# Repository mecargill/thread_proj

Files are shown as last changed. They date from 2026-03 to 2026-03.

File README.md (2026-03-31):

# Thread Project
## Overview
This project is a wearable free fall detection system implemented on an ESP32. It uses ESP_IDF. 
## Repo Structure
The documentation folder contains a user guide, diagrams, and pictures. 
The enclosure folder contains .stl files for 3D printing the enclosure. 
The code folder contains 2 subfolders. The final firmware is in the node_final folder.
The final ui, as well as some helper Python programs, are in the data_proc folder. See code/data_proc/requirements.txt for the requirements for setting up the venv.

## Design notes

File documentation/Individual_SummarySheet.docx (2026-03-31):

Name: | Matthew Cargill
Thread: | Sensing and Exploration
Brief Project Description (2-3 sentences): | This project is a wearable-free, privacy-preserving fall detection system designed for elderly individuals. It uses a combination of vibration sensing, acoustic sensing, and Wi-Fi CSI to detect motion, sound, and floor vibrations associated with a fall. By integrating multiple sensing modalities, the system improves reliability compared to single-sensor approaches.
On-campus Resources used (Makerspaces, Instructional Labs) | The Hive Makerspace
Relation to thread (1-2 sentences): | This project directly aligns with the Sensing and Exploration thread by incorporating multiple sensing modalities, including Wi-Fi, vibration, and acoustic signals. It also applies sensor fusion techniques to interpret noisy data and improve fall detection accuracy.
Why did you choose this project? | I have known several relatives/friends who were seriously injured/died because of falls – it is important for them to get help as fast as possible. Additionally, my grandmother often refused to wear her Life Alert device, so I saw firsthand the difficulties of wearable solutions. I was also interested in exploring Wi-Fi sensing, which was a new and intriguing area to me.
Final Outcome (Was the project completed): | The project was completed successfully. The final system includes a soldered protoboard implementation housed in a 3D-printed enclosure. I also developed software to interface with the device and display a graphical dashboard showing presence detection, fall detection results, and event logs. Testing demonstrated that the system can detect both falls and presence with reasonable accuracy. However, this remains a prototype, and performance could be further improved with more advanced signal processing and modeling techniques.

Innovate ECE: The Ultimate Thread Competition Summary Sheet – Individual Submission Spring 2026

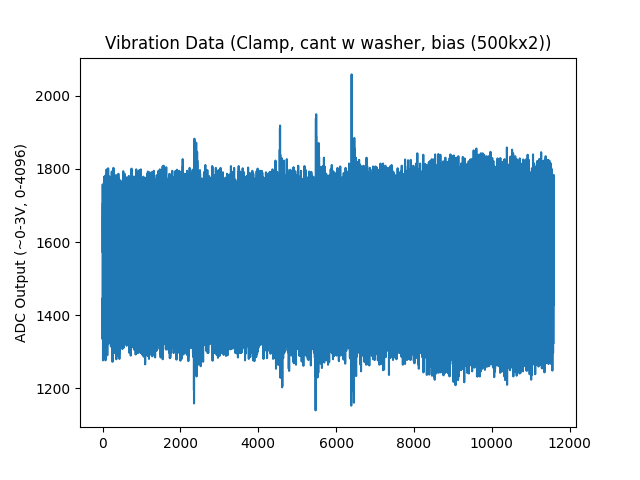
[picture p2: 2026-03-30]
documentation/pics/vib/Figure_2.png

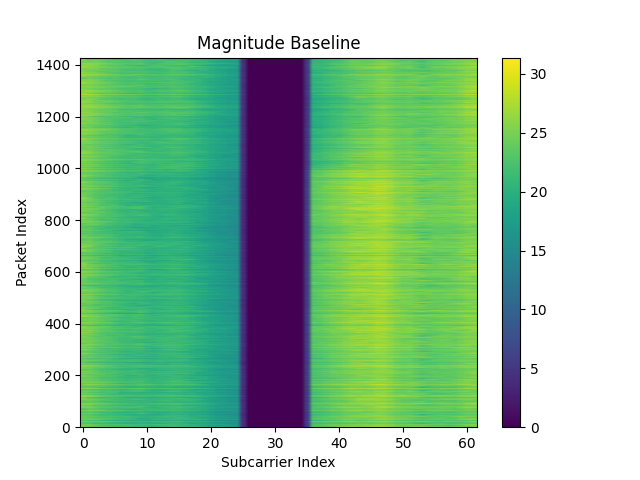
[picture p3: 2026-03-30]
documentation/pics/csi/baseline_w_dc.png

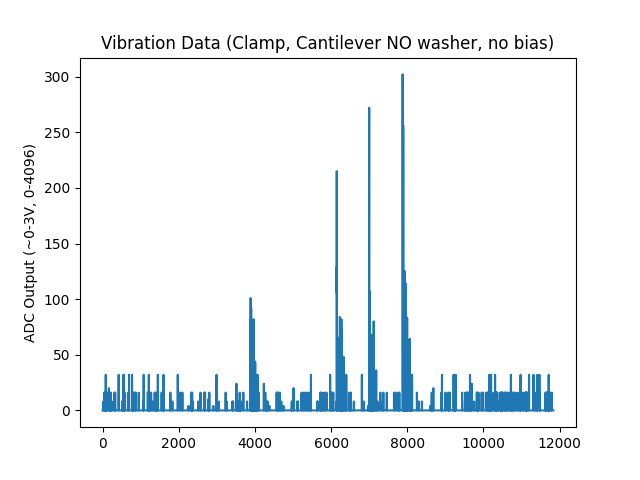
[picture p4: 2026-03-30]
documentation/pics/vib/Figure_6.png

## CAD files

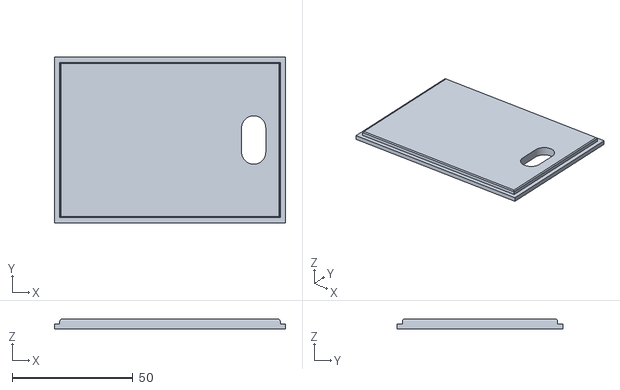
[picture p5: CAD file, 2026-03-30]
enclosure/enclosure_cap.stl
95.5 x 68.5 x 4.00

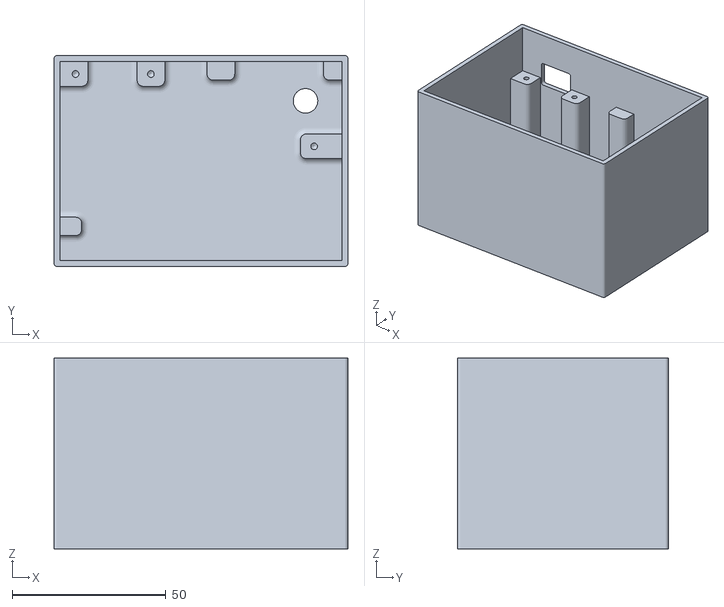
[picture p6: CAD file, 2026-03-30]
enclosure/enclosure_body.stl
95.5 x 68.5 x 62.0

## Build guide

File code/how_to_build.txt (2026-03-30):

open powershell
To build and run:
	export.ps1
	idf.py set-target esp32   (only once per project)
	idf.py menuconfig (TO ENABLE CSI IN component config->wifisettings, SET RTOS TICK to 500Hz not 100)
	idf.py build
	idf.py flash [-p COM5 (or similar)]
	idf.py monitor - to see program output
		ctrl+] to exit monitor mode

Miscellaneous
	idf.py fullclean - to clean build
	idf.py menuconfig
	idf.py create-project <project name>

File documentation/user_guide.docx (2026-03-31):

# Wearable-Free Fall Detection User Guide

# 1. Goals

The goal of this project is to use sensors to create an inexpensive fall detection system without wearables. The elderly often forget or choose not to put on health wearables, so a fall detection system that could be installed in a home or assisted living facility rather than worn could be more reliable. To preserve privacy, this project aims to avoid using cameras.

# 2. Overview of Design

### Hardware Overview

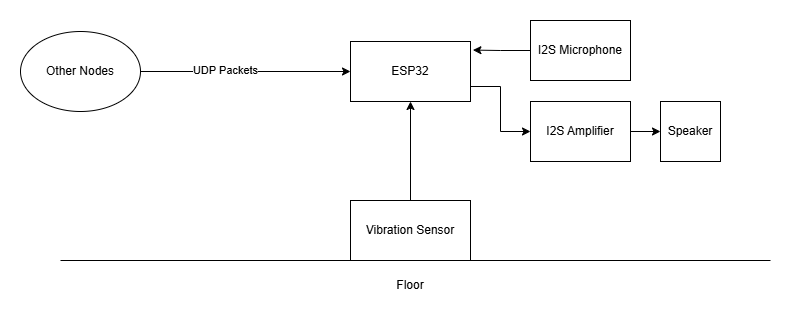
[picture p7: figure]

This system uses 3 types of sensing to detect a fall: a piezoelectric vibration sensor, a microphone, and Wi-Fi Channel State Information (CSI) sensing. The vibration sensor detects someone hitting the floor. The microphone detects the thump of a fall or presence in the room. The CSI data is used to detect changes in Wi-Fi signal propagation at different frequencies caused by motion (more information is in the resources section or here (https://www.digitalintelligence.at/wifi-signals-can-see-you-how-csi-sensing-works/)). An ESP32 will serve as the central hub where most of the processing will happen. Additionally, the speaker is used to play an alert when a fall is detected.

### Software Overview

There are 2 main sets of software in this project (repositories in resources section). The first is the C program (in repo node_final) running on the ESP32 which handles the following:

- Interfacing with microphone and speaker
- Reading and processing vibration data
- Sending and/or receiving packets
- Processing CSI data
- Depending on the mode, either streaming data for development/tuning purposes (development modes) or communicating only the results of processing to preserve privacy (normal operation mode)

The second set of software is written in Python and is run on a computer connected to the ESP32 development board’s UART to USB chip (in repo data_proc). There are multiple programs, which have the following functions:

- With ESP32 software in normal operation mode, act as a dashboard showing sensor activity and detection status
- Read/visualize streamed CSI data for development purposes
- Read/visualize streamed microphone data for development purposes
- Read/visualize streamed vibration data for development purposes

# 3. Components Required

The following components were used in this project:

- 2 ESP32 DEVKIT V1 boards
- INMP 441 Board (microphone)
- Piezoelectric Ceramic Disc
- MAX 98357 Amplifier Board
- 1 W, 8 Ohm speaker

The exact purchases are in the resources section.

# 4. Hardware Setup

Once the hardware is obtained, the connections shown below should be implemented. It is best to use a breadboard first for testing, then potentially create a more permanent implementation if desired. The provided CAD files can be used to 3D print an enclosure as well.

This setup only needs to be done on one of the ESP32s – the one which will be receiving the UDP packets and calculating the CSI.

### Connection Diagram

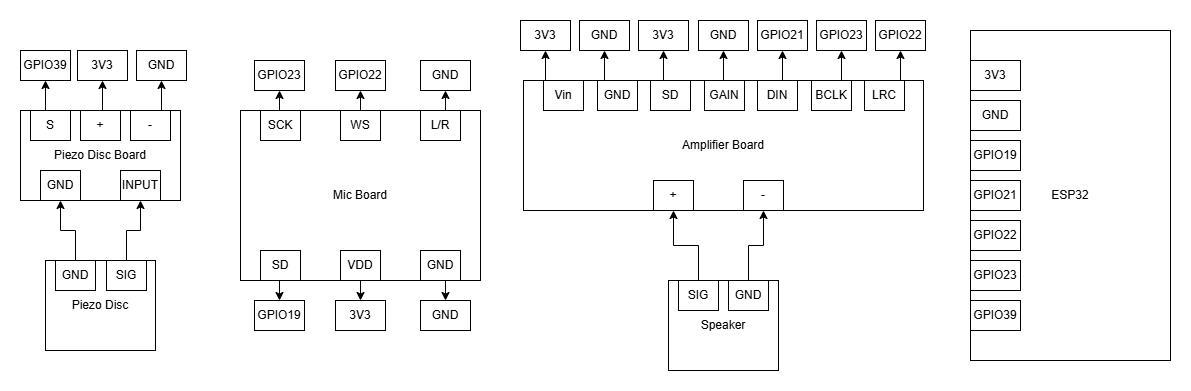
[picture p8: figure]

### DEVKIT V1 Pinout


### Example Breadboard Implementation

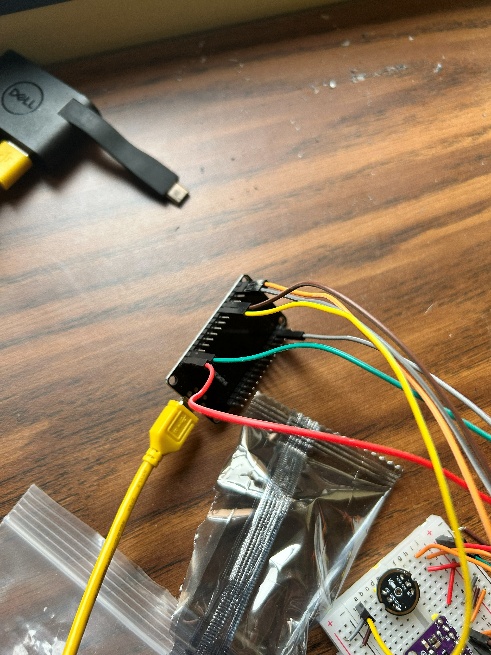
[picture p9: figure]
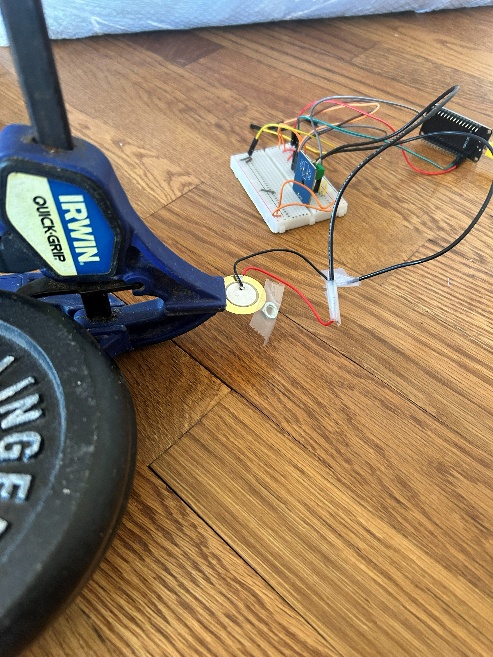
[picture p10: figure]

### Example Final Implementation

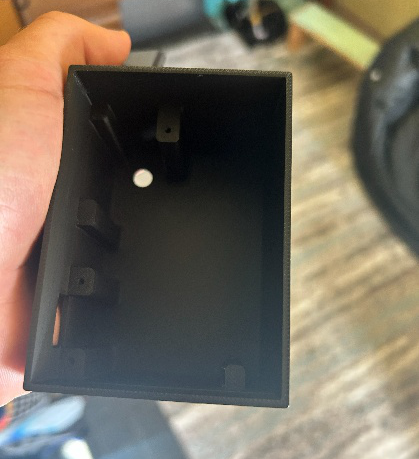
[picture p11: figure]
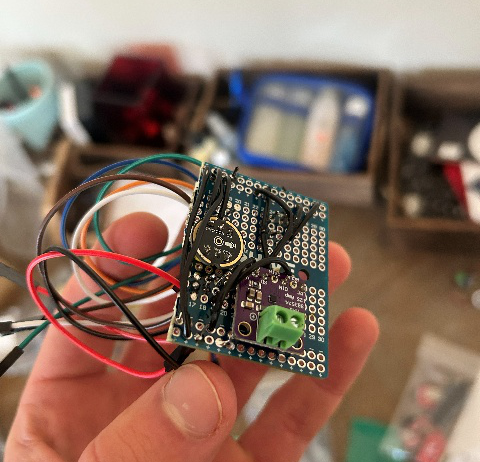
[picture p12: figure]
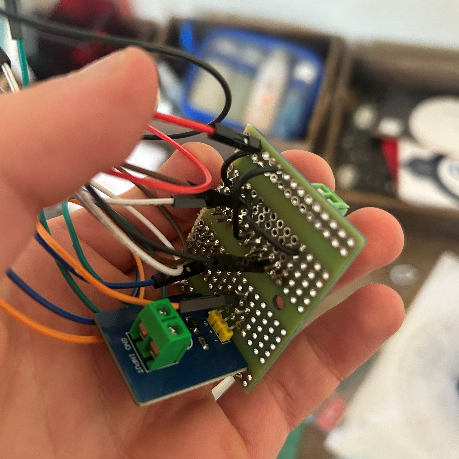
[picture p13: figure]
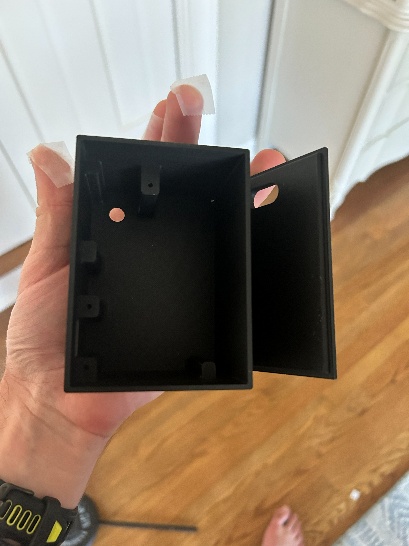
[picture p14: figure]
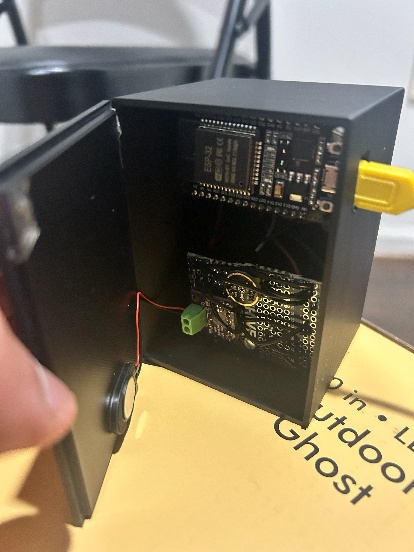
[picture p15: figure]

# 5. Software Setup

### Dependencies

This project uses the ESP-IDF framework. In addition to cloning the repository, the ESP-IDF libraries/tools need to be installed to build the code. The Espressif documentation on this process is available here (https://docs.espressif.com/projects/esp-idf/en/stable/esp32/get-started/index.html). In my case, the installer did not work and I had to clone this (https://github.com/espressif/esp-idf) repository and use the command line interface. Once the esp-idf repository is cloned, run the “install.ps1” script.

Additionally, clone the repository “node_final” from the project GitHub.

### Building

(if using the gui, refer to Espressif documentation)

In the node_final folder, run the “export.ps1” script provided by the esp-idf repository – This must be done once per terminal session in which you want to use idf.py.

To build and flash, run the following commands:

idf.py set-target esp32

idf.py menuconfig (Use this GUI to go to component config -> Wi-Fi -> enable CSI)

idf.py build

idf.py flash

You should flash this software onto 2 ESP32s – one to transmit and one to receive.

### Setting the Mode

There is a variable in the file “node_final.c” called mode. There are 4 options for the mode: NORMAL, DEV_CSI, DEV_VIB, and DEV_MIC. It must be set before building. NORMAL is for normal operation, and the others are used for data collection and tuning.

# 6. Tuning

### Test Setup

In this prototype setup, the sensor data are sensitive to the exact layout of the room, orientation of the sensors, and setup of the piezo disc. Using the DEV modes, along with some provided Python scripts, the sensor data can be streamed and visualized on a laptop to help tune threshold values.

### Microphone Tuning

(microphone is not sensitive to setup and likely doesn’t need tuning)

To stream mic data and tune, follow these steps:

- Build/flash the node_final project in DEV_MIC mode
- Activate data_proc_venv
- Run “mic_reader.py” (The port name may need to be adjusted from COM5 on different systems)
- After you test via making sound, hit ctrl + c
- Run “mic_processor.py” (The file paths will need to be adjusted to include your data)
- A graph such as this will be produced:

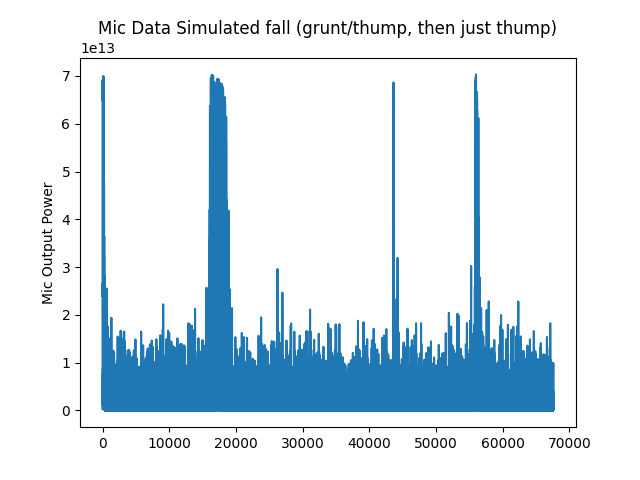
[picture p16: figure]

- Simple thresholding is used in this prototype system - a threshold of 3*10^13 would be good based on this graph
- Take the square root (ie. sqrt(3*10^13) = 5477225) and set the macro MIC_THRESHOLD to that value (in sound.c)

### CSI Tuning

The CSI data is processed with a moving average and rolling variance over 2 groups of subcarriers that were found to be sensitive to motion. Example captures of full CSI magnitudes are shown here first with no processing, then with smoothing and removal of nulled subcarriers. The variance (times window length) of the smoothed data is what is thresholded.

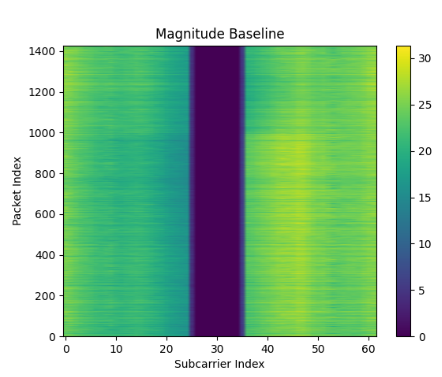
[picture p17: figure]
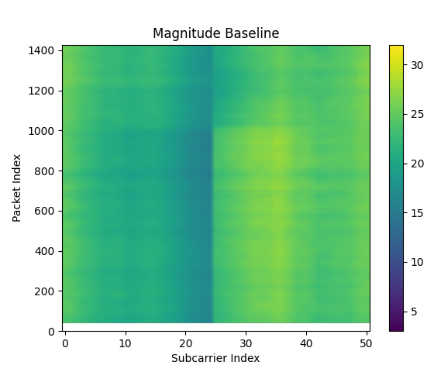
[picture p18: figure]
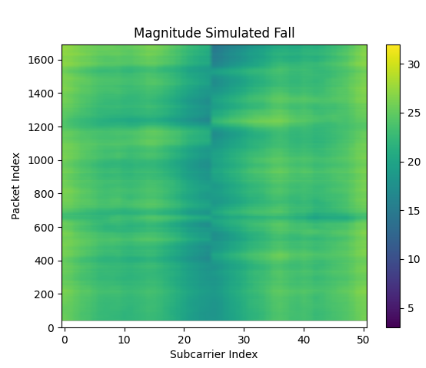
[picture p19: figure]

To stream/tune CSI data, follow these steps:

- Build/flash in DEV_CSI mode
- Run “csi_reader.py” and “csi_processor.py” similarly to the mic
- A graph like this will be produced:

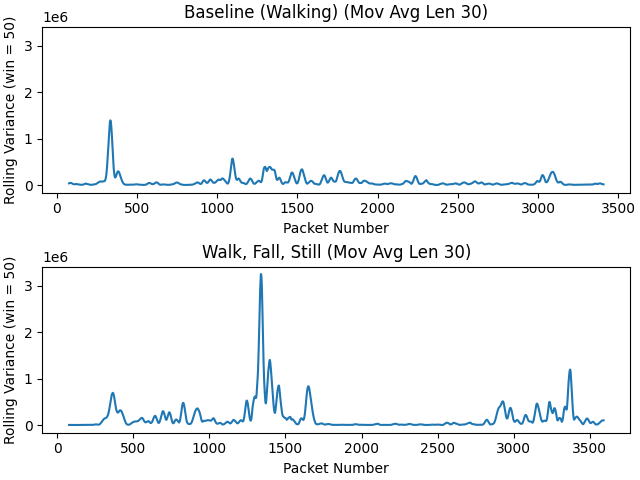
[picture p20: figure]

- Pick 2 thresholds – one for just walking, and one for large amounts of motion, both above the noise floor (ex. Here, 0.1e6 and 0.65e6 would work)
- Set the macros CSI_THRESHOLD_LOW and HIGH (in csi_rx.c)

### Vibration Tuning

The piezo disc is very sensitive to the setup. Multiple configurations may need to be tested. An example configuration is shown here:

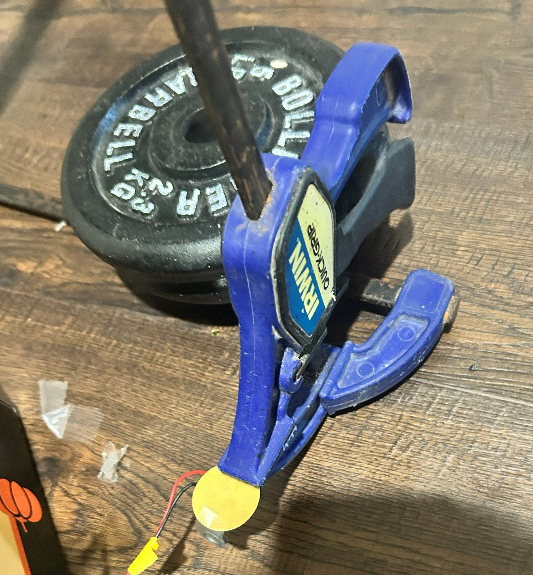
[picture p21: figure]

I found the most success by using clamps to cantilever, a weight on the end, and weights to couple the setup to the floor (ideally wood). To keep maximum sensitivity, I avoided pins with pulldown resistors and avoided biasing (as shown below, these attenuate the signal). Because of this, the ADC pin is mostly floating and drifts somewhat. For that reason, the vibration data has an adaptive threshold (shown in the orange line below).

To stream/tune vibration data follow these steps:

- Build in DEV_VIB mode
- Run “vib_reader.py” and “vib_processor.py” similarly to the mic
- A graph like these will be produced:

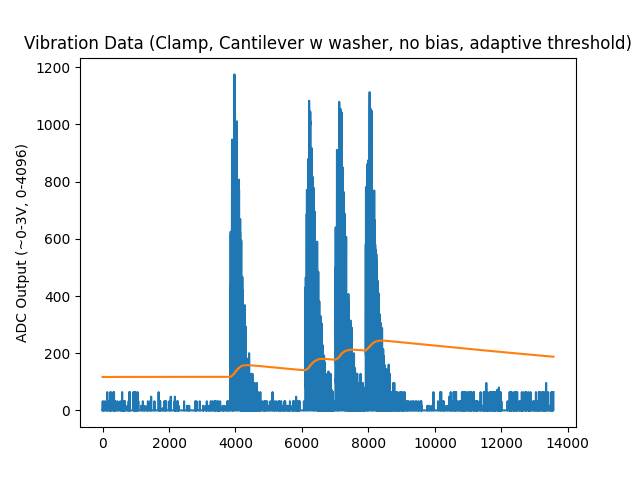
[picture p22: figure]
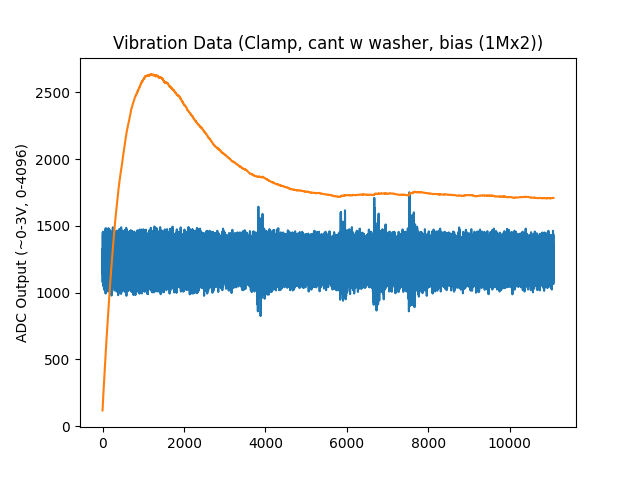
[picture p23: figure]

- The orange line shows what the threshold would have been. Adjust thresh_factor until it falls above the noise level and set the macro VIB_THRESH_FACTOR (in vib.c)
- It is recommended to take several data collects over time and test different setups

# 7. Final Product

If the CAD files are used to 3D print an enclosure (optional), the final product looks like this:

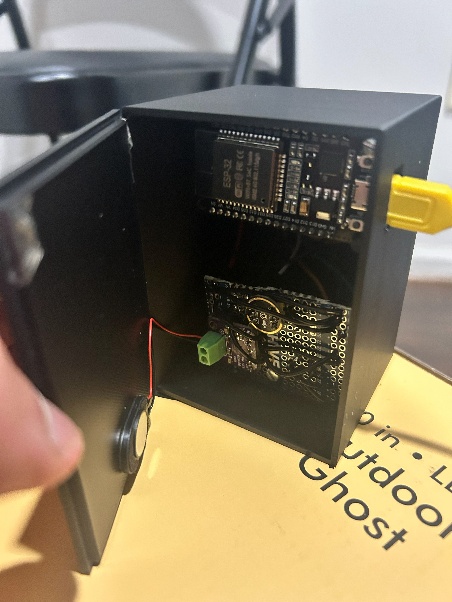
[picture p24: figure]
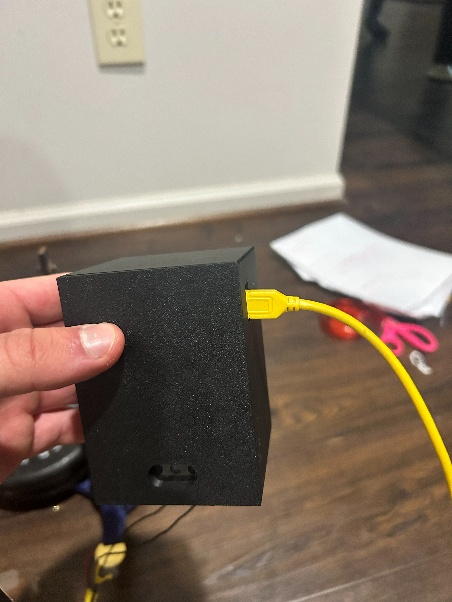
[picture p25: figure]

After setting mode to NORMAL, the program “ui.py” can be used to produce a dashboard that looks like this:

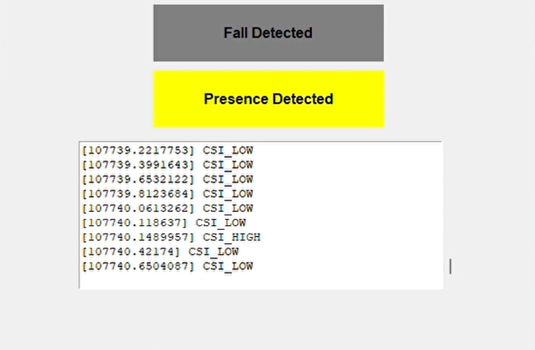
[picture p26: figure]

To use the final product, follow these steps:

- Make sure both ESP32s are flashed in NORMAL mode
- Power the ESP32 used for the transmit role first – it will detect that no transmitters exist and take that role automatically
- Then, power the ESP32 (hooked up to sensors) used for the receive role – it will find the transmitter and take the receive role automatically
- With the receive ESP32 connected to a computer via the UART to USB chip on the DEVKIT, run “ui.py”

When a fall is detected, the device will beep and the fall detected icon in the dashboard will light up red. It also detects presence. The events causing the detections are printed via the scrolling textual log.

# 8. Resources

### GitHub Repo

https://github.com/mecargill/thread_proj/tree/main

### Components

https://www.amazon.com/dp/B0FHWB5VFW?ref=ppx_yo2ov_dt_b_fed_asin_title

https://www.amazon.com/dp/B0B18FW97Z?ref=ppx_yo2ov_dt_b_fed_asin_title

https://www.amazon.com/dp/B0B18FW97Z?ref=ppx_yo2ov_dt_b_fed_asin_title

https://www.amazon.com/dp/B0C7C2HQ7P?ref=ppx_yo2ov_dt_b_fed_asin_title

https://www.amazon.com/dp/B0FC5YJD3S?ref=ppx_yo2ov_dt_b_fed_asin_title

### Espressif Docs

https://docs.espressif.com/projects/esp-idf/en/stable/esp32/get-started/index.html

https://github.com/espressif/esp-idf

https://docs.espressif.com/projects/esp-idf/en/stable/esp32/api-reference/index.html

https://mischianti.org/doit-esp32-dev-kit-v1-high-resolution-pinout-and-specs/

### CSI Sensing Information

https://www.digitalintelligence.at/wifi-signals-can-see-you-how-csi-sensing-works/

https://info.support.huawei.com/info-finder/encyclopedia/en/CSI+Sensing.html

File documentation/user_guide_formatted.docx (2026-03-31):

Wearable-Free Fall Detection System

User Guide

ESP32-based sensor fusion for privacy-preserving fall detection

# 1. Goals

This project creates an inexpensive, camera-free fall detection system that does not require wearables. Because the elderly often forget or choose not to wear health devices, a system installable in a home or assisted living facility can be more reliable. By avoiding cameras, the design also preserves resident privacy. Additionally, by using simple Wi-Fi hardware rather than expensive radar hardware, the system can be made inexpensively.

# 2. Overview of Design

## Hardware Overview

This system uses three sensing modalities to detect a fall:

- Piezoelectric vibration sensor: detects impact with the floor
- Microphone: detects the thump of a fall or presence in the room
- Wi-Fi CSI (Channel State Information): detects motion-induced changes in signal propagation

An ESP32 serves as the central processing hub, and a speaker plays an audible alert on fall detection.


💡 For more background on CSI sensing technology, see the Resources section.

## Software Overview

ESP32 Firmware (C) (folder in repo: code/node_final)

Handles all on-device processing:

- Interfacing with the microphone and speaker
- Reading and processing vibration data
- Sending and receiving UDP packets
- Processing CSI data
- Development modes: streaming raw sensor data for tuning
- Normal operation mode: transmitting only detection results to preserve privacy

Python Scripts (folder in repo: code/data_proc)

Run on a computer connected to the ESP32 via USB:

- Dashboard showing sensor activity and detection status (normal mode)
- Visualization tools for CSI, microphone, and vibration data (development modes)

# 3. Components Required

The following components are needed. Purchase links are in the Resources section.

Component | Details
ESP32 DEVKIT V1 | ×2 Main microcontroller boards
INMP441 Board | I2S MEMS Microphone
Piezoelectric Ceramic Disc | Vibration / impact sensor
MAX98357 Amplifier Board | I2S audio amplifier
Speaker | 1 W, 8 Ohm

# 4. Hardware Setup

Connect components as shown in the diagrams below. A breadboard is recommended for initial testing before creating a permanent implementation. Optional 3D-printable enclosure CAD files are available in the project repository.

💡 Only the receiver ESP32 needs sensors connected. The second ESP32 acts solely as a Wi-Fi packet transmitter.

## Connection Diagram


## DEVKIT V1 Pinout


## Example Breadboard Implementation


## Example Final Implementation

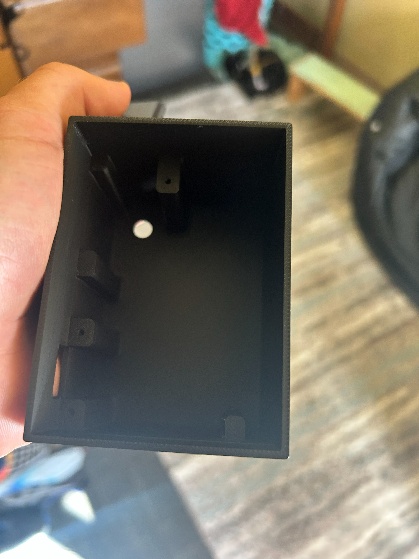
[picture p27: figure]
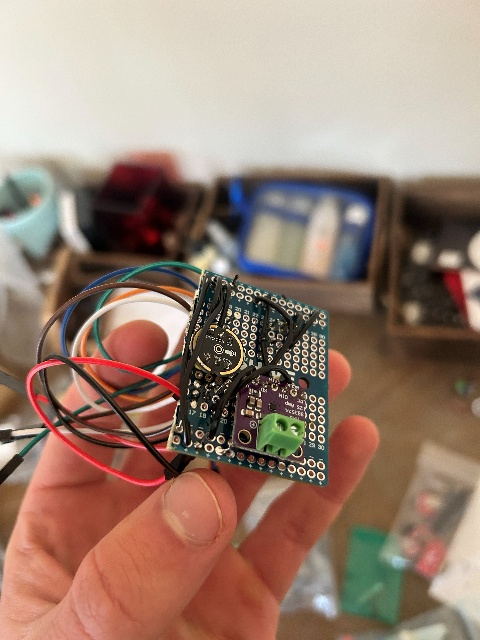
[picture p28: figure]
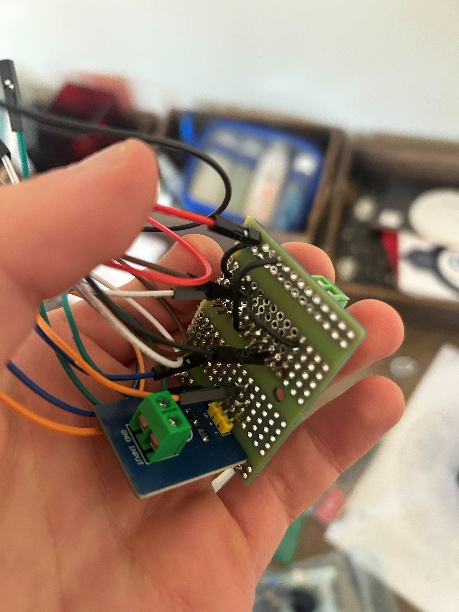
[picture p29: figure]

# 5. Software Setup

## Dependencies

1. Install ESP-IDF using the official Espressif getting started guide (link in Resources). If the installer fails, clone the esp-idf repository manually and run:

install.ps1

2. Clone the thread_proj repository from the project GitHub (link in Resources).

## Building & Flashing

💡 If using the ESP-IDF GUI rather than CLI, refer to Espressif’s IDE documentation.

Run the following commands from the code/node_final directory. The export script must be run once per terminal session (add esp-idf directory to PATH for convenience):

export.ps1 # Run once per terminal session

idf.py set-target esp32

idf.py menuconfig # Component Config > Wi-Fi > Enable CSI

idf.py build

idf.py flash

💡 Flash this firmware onto both ESP32s. Each board will automatically negotiate its role (transmitter or receiver) at power-on.

## Operating Modes

Before building, set the mode variable in node_final.c to one of the following options:

Mode | Description
NORMAL | Normal operation: transmits detection results only
DEV_CSI | Streams raw CSI data for development/tuning
DEV_VIB | Streams raw vibration data for development/tuning
DEV_MIC | Streams raw microphone data for development/tuning

# 6. Tuning

Sensor thresholds depend on room layout, sensor placement, and floor type. Use the DEV modes with the provided Python scripts to stream and visualize sensor data before finalizing values.

## Microphone Tuning

💡 The microphone is not sensitive to physical setup and may not require tuning.

Steps to tune:

- Build and flash in DEV_MIC mode
- Activate the data_proc_venv Python environment
- Run mic_reader.py (adjust COM port if not on Windows/COM5), make some test sounds, then press Ctrl+C
- Run mic_processor.py (update file paths to your collected data)
- A graph such as this one will be produced:


Select a threshold from the graph. Take the square root (convert power to amplitude) and set the macro in sound.c:

// Example: threshold = 3e13, sqrt(3e13) ≈ 5477225

#define MIC_THRESHOLD 5477225

## CSI Tuning

Because it depends on antenna patterns and multipath reflections, CSI is sensitive to room layout and antenna orientation. CSI data is processed using a moving average and rolling variance over two subcarrier groups. The plots below show example raw magnitudes and smoothed data.

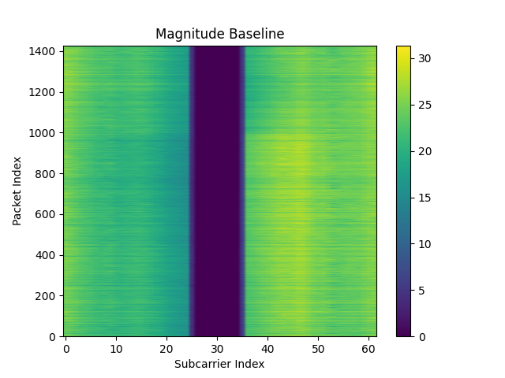
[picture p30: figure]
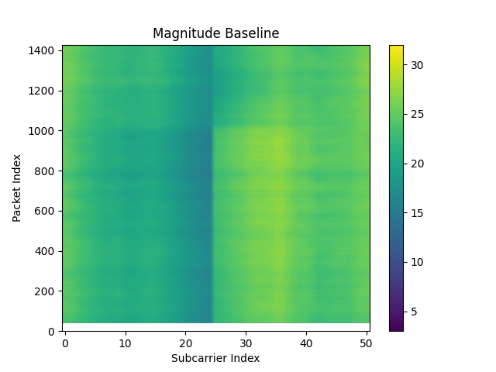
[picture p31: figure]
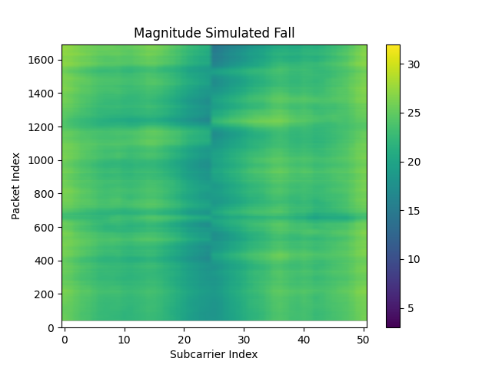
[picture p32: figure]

Steps to tune:

- Build and flash in DEV_CSI mode
- Run csi_reader.py and csi_processor.py
- A graph such as this one will be produced:


Select two thresholds: one for walking, one for large motion. Both should be above the noise floor. Set the macros in csi_rx.c:

#define CSI_THRESHOLD_LOW 100000 // e.g. 0.1e6 for walking

#define CSI_THRESHOLD_HIGH 650000 // e.g. 0.65e6 for large motion

## Vibration Tuning

The piezo disc is highly sensitive to its physical setup. One possible configuration uses clamps to cantilever the disc with a weight on the end, plus weights to couple it to the floor. Wood floors work best.

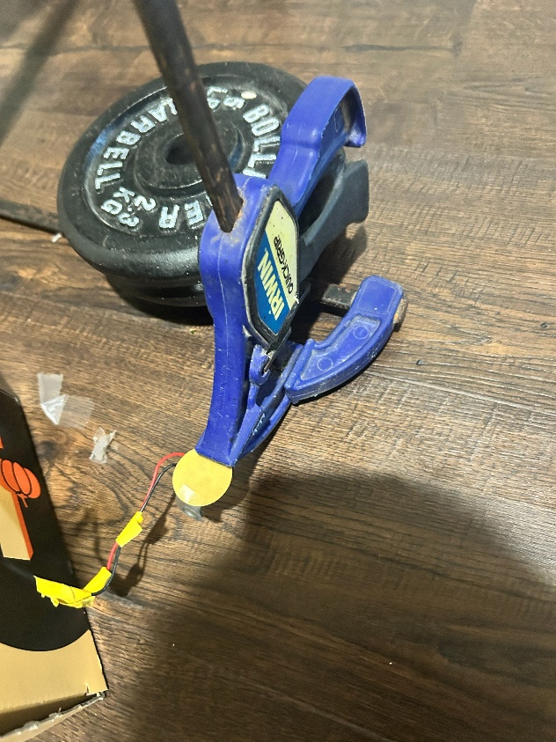
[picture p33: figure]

💡 Avoid pulldown resistors and biasing on the ADC pin. These attenuate the signal (as shown in image below). An adaptive threshold compensates for the floating pin.

Steps to tune:

- Build and flash in DEV_VIB mode
- Run vib_reader.py and vib_processor.py
- A graph such as this one will be produced:


Adjust thresh_factor until the adaptive threshold (orange line) sits above the noise floor, then set the macro in vib.c:

#define VIB_THRESH_FACTOR <your_value>

💡 Collect data at different times and with different physical configurations to find the most robust setup.

# 7. Final Product

With the 3D-printed enclosure, the assembled device looks like this:


The program ui.py opens the monitoring dashboard when device is in NORMAL mode:

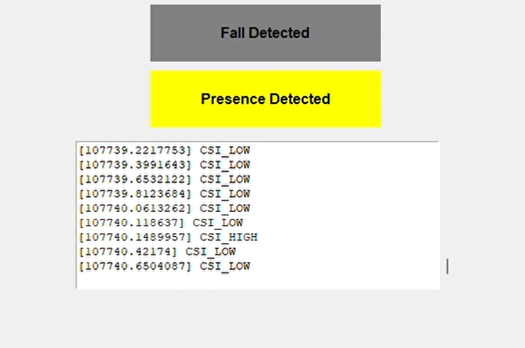
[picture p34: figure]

## Operating the Device

1. Ensure both ESP32s are flashed in NORMAL mode.

2. Power on the transmitter ESP32 first. It will automatically detect no other transmitter and claim that role.

3. Power on the receiver ESP32 (with sensors attached). It will find the transmitter and take the receiver role.
4. Connect the receiver to a computer via USB and run ui.py to launch the dashboard.

When a fall is detected, the device beeps and the fall indicator on the dashboard lights up red. Presence detection is indicated by the yellow box. A scrolling log shows the events that triggered each detection.

# 8. Resources

## GitHub Repository

github.com/mecargill/thread_proj

## Component Purchases

ESP32 DEVKIT V1 boards (https://www.amazon.com/dp/B0C7C2HQ7P?ref=ppx_yo2ov_dt_b_fed_asin_title&th=1)

INMP441 Microphone Board (https://www.amazon.com/dp/B0FBWQF74T?ref=ppx_yo2ov_dt_b_fed_asin_title&th=1)

MAX98357 Amplifier Board (https://www.amazon.com/dp/B0FHWB5VFW?ref=ppx_yo2ov_dt_b_fed_asin_title)

Speaker (1W, 8 Ohm) (https://www.amazon.com/dp/B0FC5YJD3S?ref=ppx_yo2ov_dt_b_fed_asin_title)

Piezoelectric Disc (https://www.amazon.com/dp/B0B18FW97Z?ref=ppx_yo2ov_dt_b_fed_asin_title)

## Espressif / ESP-IDF Documentation

ESP-IDF Getting Started Guide (https://docs.espressif.com/projects/esp-idf/en/stable/esp32/get-started/index.html)

ESP-IDF GitHub Repository (https://github.com/espressif/esp-idf)

ESP-IDF API Reference (https://docs.espressif.com/projects/esp-idf/en/stable/esp32/api-reference/index.html)

DOIT ESP32 DEVKIT V1 Pinout (https://mischianti.org/doit-esp32-dev-kit-v1-high-resolution-pinout-and-specs/)

## CSI Sensing Background

How CSI Sensing Works (Digital Intelligence) (https://www.digitalintelligence.at/wifi-signals-can-see-you-how-csi-sensing-works/)

CSI Sensing Encyclopedia (Huawei) (https://info.support.huawei.com/info-finder/encyclopedia/en/CSI+Sensing.html)

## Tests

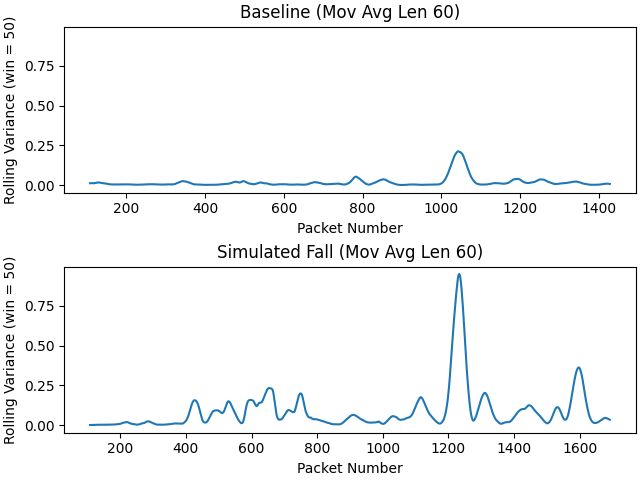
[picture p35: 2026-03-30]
documentation/pics/csi/param_test20.png

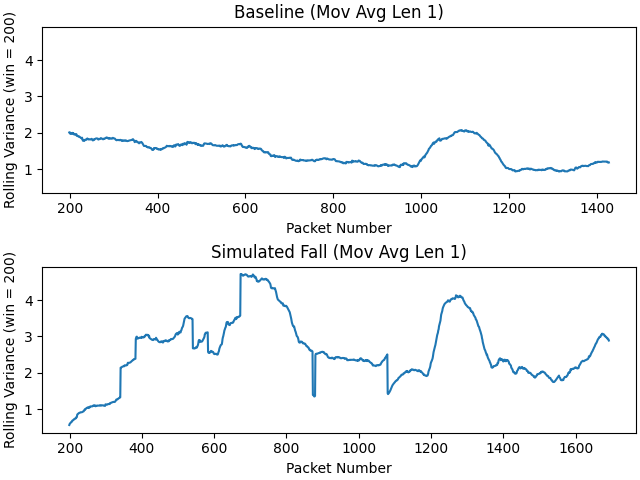
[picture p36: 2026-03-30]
documentation/pics/csi/param_test02.png

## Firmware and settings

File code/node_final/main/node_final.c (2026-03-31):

#include <stdio.h>

#include "esp_wifi.h" 

#include "csi_rx.h"
#include "csi_tx.h"
#include "uart.h"
#include "vib.h"
#include "sound.h"
#include "wifi_common.h"
#include "common.h"

#include "freertos/FreeRTOS.h" 
#include "freertos/task.h"  
#include "esp_system.h"        
#include "esp_log.h"           
#include "esp_err.h"

#include "driver/uart.h"

static const char *tag = "[MAIN]";
enum Mode mode = NORMAL;
bool uart_ready = false;

void app_main(void)
{
   
    ESP_LOGI(tag, "Starting up...");
    

    wifi_common_setup();
    set_as_sta();
    esp_wifi_start();

    if (an_ap_already_exists())
    {
        ESP_LOGI(tag, "AP found, taking RX role");
        enable_csi_rx();
        //in this case there is now a callback to recieve csi and sending       
    }
    else
    {     
        ESP_LOGI(tag, "AP not found, taking TX role");   
        esp_wifi_stop(); //You can't switch modes while wifi is running
        set_as_ap();
        esp_wifi_start();
        enable_csi_tx();
        //in this case there is now a background task to send udp packets
    }

    sound_init(); //now there is a task reading mic data 
    vib_init(); //now there is a callback to send adc data 
    
     
    if (mode == NORMAL)
    {
        uart_init(115200); 
    }
    else
    {
        vTaskDelay(pdMS_TO_TICKS(500));//to let any error logs show up before disabling
        esp_log_level_set("*", ESP_LOG_NONE); //to not interfere with uart0 data streaming 
        uart_init(921600);
        uart_ready = true; 
    }

}

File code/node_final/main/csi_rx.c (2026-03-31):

#include <stdio.h>
//standard esp
#include "freertos/FreeRTOS.h" // The OS kernel
#include "freertos/task.h" 
#include "freertos/queue.h"
#include "esp_system.h"        // Basic ESP32 system functions
#include "esp_log.h"           
#include "esp_err.h"
//specific
#include "nvs_flash.h"        
#include "esp_wifi.h"          
#include "esp_event.h"         
#include "esp_netif.h"
#include "esp_mac.h"
#include "esp_timer.h"
#include "driver/uart.h"

#include "wifi_common.h"
#include "common.h"
#include "uart.h"


//These indices are INCLUDING the first word that is usually invalid (2 subcarriers worth) - indices in terms of subcarriers
#define CSI_SUBC_SET1_MIN_INDEX 17
#define CSI_SUBC_SET1_MAX_INDEX 27 //not inclusive
#define CSI_SUBC_SET2_MIN_INDEX 38
#define CSI_SUBC_SET2_MAX_INDEX 48 //not inclusive
//thresholds in terms of rolling variance of window length 50 of squared magnitudes of csi data
#define CSI_THRESHOLD_LOW 100000
#define CSI_THRESHOLD_HIGH 650000
#define CSI_IGNORE_LEN 20
#define CSI_MOV_AVG_LEN 30
#define CSI_ROL_VAR_LEN 50



static const char *tag = "[CSI_STA/RX]";

static QueueSetHandle_t csi_queue;

typedef struct {
    uint16_t avg_set1;
    uint16_t avg_set2;
} csi_mag_sq_t;

void set_as_sta()
{
    ESP_LOGI(tag, "Setting as STA");
    esp_netif_create_default_wifi_sta();//creates a station interface

    esp_wifi_set_mode(WIFI_MODE_STA);

    wifi_config_t wifi_config = {
        .sta = {
            //the id of the ap that will be transmitting - left it open
            .ssid = SSID
        }
    };
    esp_wifi_set_config(WIFI_IF_STA, &wifi_config);//configures wifi interface
}

//I could have just called connect and handled the disconnected event, but this seemed a bit simpler
//It's blocking, so it keeps everything linear
bool an_ap_already_exists()
{
    ESP_LOGI(tag, "Checking if AP exists");
    wifi_scan_config_t scan_config = {
        .ssid = (uint8_t *)SSID,
        .show_hidden = true
    };

    ESP_ERROR_CHECK(esp_wifi_scan_start(&scan_config, true)); //true for blocking

    uint16_t ap_count = 0;
    ESP_ERROR_CHECK(esp_wifi_scan_get_ap_num(&ap_count));
    
    return ap_count > 0;

}

void csi_proc_stream(int8_t *csi_data, int start, uint16_t num_valid_samples)
{
    int64_t tstamp_us = esp_timer_get_time(); //8 bytes  
    static uint8_t start_bytes[2] = START_BYTES;
    static uint8_t end_bytes[2] =   END_BYTES;
    if (uart_ready)
    {
        uart_write_bytes(UART_NUM_0, start_bytes, 2);
        uart_write_bytes(UART_NUM_0, &num_valid_samples, 2);
        uart_write_bytes(UART_NUM_0, &tstamp_us, 8);
        uart_write_bytes(UART_NUM_0, csi_data+start, num_valid_samples*2);
        uart_write_bytes(UART_NUM_0, end_bytes, 2);
    }
    
}

void csi_proc_normal(int8_t *csi_data, uint16_t len)
{
    uint32_t mag_sq_sum1 = 0;
    static const uint32_t sz1 = CSI_SUBC_SET1_MAX_INDEX - CSI_SUBC_SET1_MIN_INDEX;

    uint32_t mag_sq_sum2 = 0;
    static const uint32_t sz2 = CSI_SUBC_SET2_MAX_INDEX - CSI_SUBC_SET2_MIN_INDEX;

    csi_mag_sq_t result;

    BaseType_t high_task_wakeup = pdFALSE;
    //avg the magnitude squared of the two subcarrier sets and write to queue for processing
    //indices include the potentially invalid first word (we don't use it anyways either way)
    if (2*CSI_SUBC_SET2_MAX_INDEX <= len)
    {
        for (int i = CSI_SUBC_SET1_MIN_INDEX; i < CSI_SUBC_SET1_MAX_INDEX; i++)
        {
            int csi_i = csi_data[2*i];
            int csi_q = csi_data[2*i + 1];
            mag_sq_sum1 += csi_i*csi_i + csi_q*csi_q;
        }
        result.avg_set1 = mag_sq_sum1/sz1;


        for (int i = CSI_SUBC_SET2_MIN_INDEX; i < CSI_SUBC_SET2_MAX_INDEX; i++)
        {
            int csi_i = csi_data[2*i];
            int csi_q = csi_data[2*i + 1];
            mag_sq_sum2 += csi_i*csi_i + csi_q*csi_q;
        }
        result.avg_set2 = mag_sq_sum2/sz2;


        xQueueSendFromISR(csi_queue, &result, &high_task_wakeup);
        //if pushing to queue woke up a task, go to it immediately without waiting for tick
        portYIELD_FROM_ISR(high_task_wakeup);
    }   
    
}

void csi_handler(void *ctx, wifi_csi_info_t *data)
{
    int8_t *csi_data = data->buf;

    

    if (mode == DEV_CSI)
    {
        int start = (data->first_word_invalid) ? 4 : 0; //word is 32 bits, 4 bytes, 2 subcarriers
        uint16_t num_valid_samples = (data->len - start)/2; 
        csi_proc_stream(csi_data, start, num_valid_samples);
    }
    else
    {
        csi_proc_normal(csi_data, data->len);
    }
}


//There are 2 types of CSI events - low is for general presence detection (walking, etc.), high is for 
//extreme motion
void csi_threshold(uint64_t rol_var)
{
    static bool last_was_below_low;
    static bool last_was_below_high;

    static int num_since_det_low = CSI_IGNORE_LEN;
    static int num_since_det_high = CSI_IGNORE_LEN;

    static uint16_t low_tag = CSI_TAG_LOW;
    static uint16_t high_tag = CSI_TAG_HIGH;

    num_since_det_high++;
    num_since_det_low++;

    if (rol_var > CSI_THRESHOLD_LOW)
    {
        if (last_was_below_low && num_since_det_low > CSI_IGNORE_LEN) 
        {
            notify_host(low_tag);
            num_since_det_low = 0;
        }
        last_was_below_low = false;
    }
    else
    {
        last_was_below_low = true;
    }

    if (rol_var > CSI_THRESHOLD_HIGH)
    {
        if (last_was_below_high && num_since_det_high > CSI_IGNORE_LEN) 
        {
            notify_host(high_tag);
            num_since_det_high = 0;
        }
        last_was_below_high = false;
    }
    else
    {
        last_was_below_high = true;
    }


}

typedef struct {
    uint16_t buf[CSI_MOV_AVG_LEN];
    uint32_t sum;
    uint16_t avg;
} mov_avg_info_t;

typedef struct {
    uint16_t buf[CSI_ROL_VAR_LEN];
    uint32_t sum;
    uint64_t sum_sq;
} rol_var_info_t;
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
